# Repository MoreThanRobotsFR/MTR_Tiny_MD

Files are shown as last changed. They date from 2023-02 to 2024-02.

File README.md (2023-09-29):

# MTR_Tiny_MD
<p align="center">

 IMAGE ALT TEXT (https://www.youtube.com/watch?v=xt2y6jAOXSE "DRV8316 + RP2040 | SimpleFOC | MTR Tiny Motor Driver")

</p>

# Changelog

This changelog provides a summary of the updates and changes made to the Motor Driver - MTR Tiny Motor Driver.

## Revision History:

- Rev: 1.0.3 Date: 20/03/2023
    - Update: Stepper motor controller board
    - Update: Brushless motor controller board

- Rev: 1.1.0 Date: 10/05/2023
    - Update: Overview Board w/ BLDC + Support

- Rev: 1.2.0 Date: 14/09/2023
    - Update: Power Delivery controller
    - Update: Correct SPI wrong connection
    - Update: Update net design (power net)
    - Update: Rx & Tx pinout can be used for CAN

- Rev: 1.2.2 Date: 20/09/2023
    - Update: Add low pass filter for Reset button

# Overview

<p align="center">
    <a>
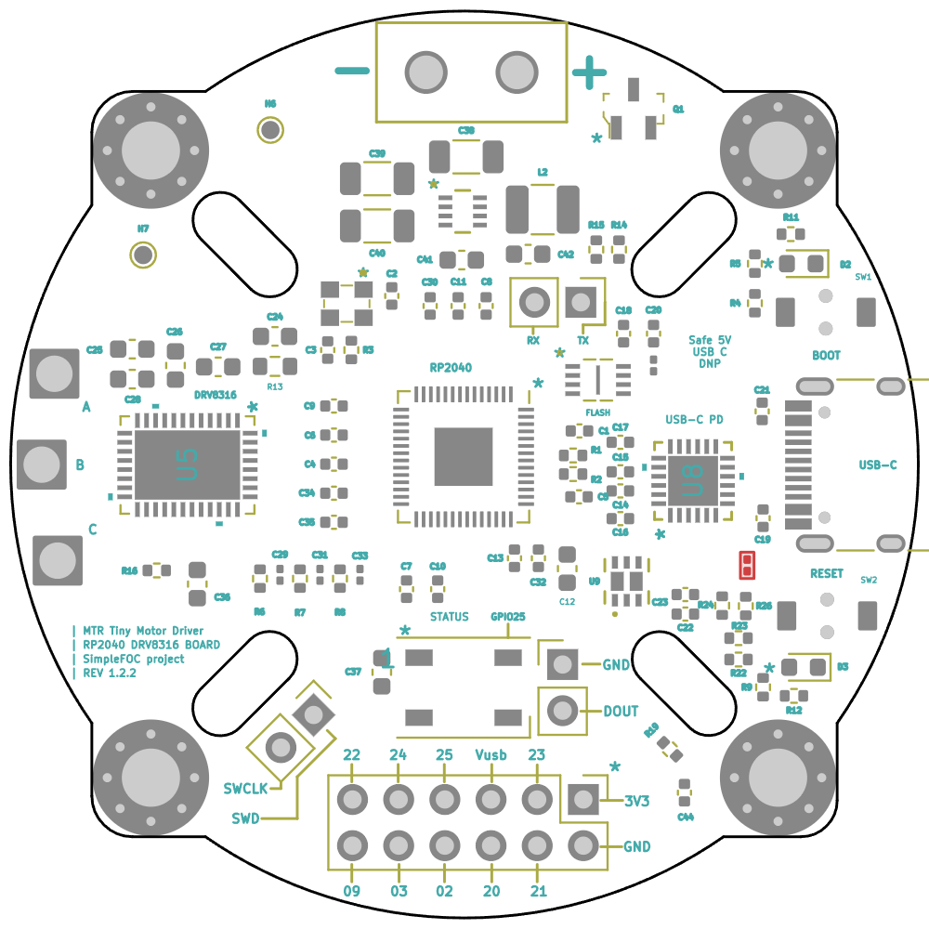
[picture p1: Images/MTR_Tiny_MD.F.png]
        
    </a>
    <br>
    <em>Front</em>
</p>

<p align="center">
    <a>
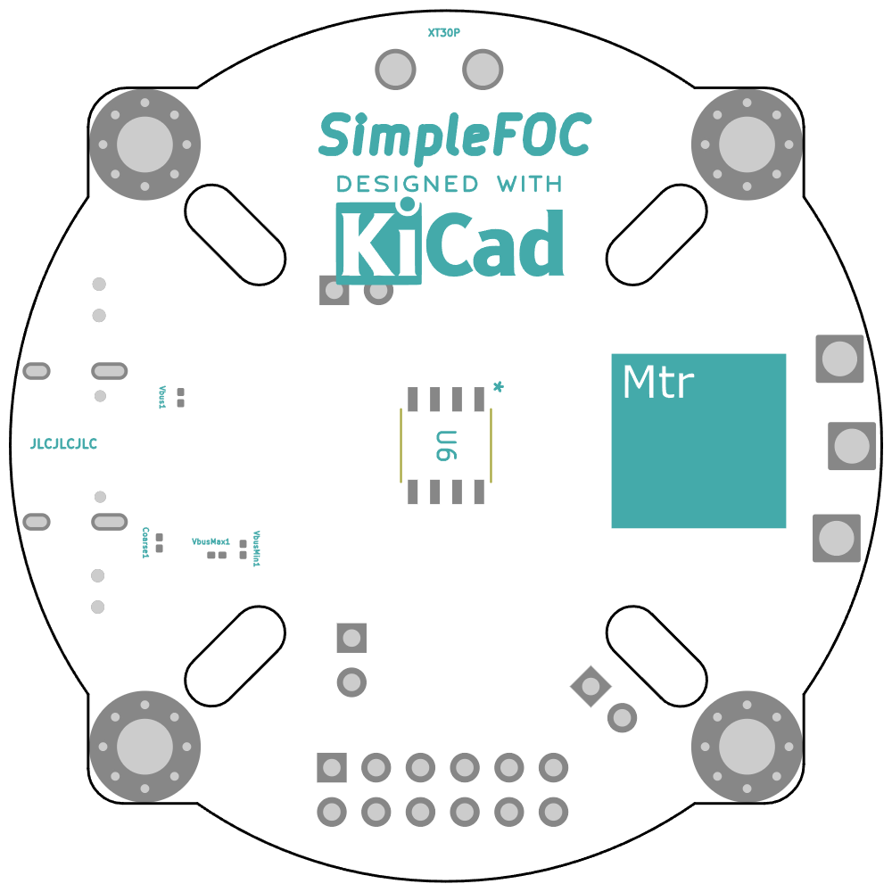
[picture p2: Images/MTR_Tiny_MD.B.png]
        
    </a>
    <br>
    <em>Back</em>
</p>

**Note:** 
- Please refer to the [schematic](Docs/MTR_Tiny_MD.pdf) for detailed information about the MTR Tiny Motor Driver.
- Please refer to the [presentation](Docs/MTR_MD.pdf) for detailed information about the MTR Tiny Motor Driver.
- Please refer to the [bill of materials](Hardware/MTR_Tiny_MD/bom/bom.html) for detailed information about the MTR Tiny Motor Driver.

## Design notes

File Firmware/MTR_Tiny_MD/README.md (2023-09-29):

# Code in Progress

This repository contains an Arduino code that is still in progress. The code is designed to control a BLDC (Brushless DC) motor using the SimpleFOC library and a DRV8316 driver. It also utilizes a magnetic sensor for position sensing and an Adafruit NeoPixel for visual feedback.

## Requirements
To run this code, you need the following components:
- Raspberry Pi RP2040 board (or any other Arduino board supported by the SimpleFOC library)
- DRV8316 driver board
- Magnetic sensor (AS5600 I2C)
- Adafruit NeoPixel strip

## Installation
1. Download and install PlatformIO IDE from the [official website](https://platformio.org/install).
2. Open PlatformIO IDE and create a new project.
3. Copy the code from this repository and replace the existing `main.cpp` file in your project with it.
4. Connect your Arduino board to your computer using a USB cable.
5. Open the `platformio.ini` file in your project and select the appropriate board and port under the `[env:your_board_name]` section.
6. Save the `platformio.ini` file.
7. Build and upload the code to your Arduino board using the PlatformIO IDE.

## Usage
1. Connect the DRV8316 driver board and the magnetic sensor to the appropriate pins on your Arduino board. Refer to the comments in the code for the pin assignments.
2. Connect the motor to the DRV8316 driver board.
3. Connect the Adafruit NeoPixel strip to the appropriate pin on your Arduino board. Refer to the comments in the code for the pin assignment.
4. Open the serial monitor in the PlatformIO IDE or use an external serial communication tool, such as Arduino Serial Monitor or PuTTY.
5. Set the baud rate to 115200.
6. Once the code is uploaded and running on your Arduino board, you can use the serial terminal to set the target velocity of the motor. Type "T" followed by the desired velocity and press enter.

## Current Status and Future Development
The code is currently a work in progress and may have bugs or incomplete functionality. The main functionality of controlling the BLDC motor using the SimpleFOC library and the DRV8316 driver is implemented. The code also includes features for monitoring motor variables and displaying the status of the DRV8316 driver using the serial monitor.

Future development plans for this code may include:
- Adding additional functionality, such as position control or torque control.
- Optimizing the code for better performance or efficiency.
- ...and more!

## Note
Please note that this code is still in progress and may not be fully functional or optimized. Use it at your own risk and make sure to test it in a controlled environment before using it in any critical or potentially dangerous applications. Contributions and feedback are welcome to help improve the code.

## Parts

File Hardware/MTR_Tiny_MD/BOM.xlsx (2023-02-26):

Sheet: BOM
Item | Qty | Reference(s) | Value | LibPart | Footprint | Datasheet
34 | 1 | Q1 | AO3401A | dk_Transistors-FETs-MOSFETs-Single:AO3401A | digikey-footprints:SOT-23-3 | http://aosmd.com/res/data_sheets/AO3401A.pdf
45 | 1 | U2 | W25Q16JVUXIQ | W25Q16JVUXIQ:W25Q16JVUXIQ | Personal:W25Q16JVUXIQ | https://www.mouser.fr/datasheet/2/949/w25q16jv_spi_revg_03222018_plus-1489727.pdf
47 | 1 | U4 | TPS71933-33DRVR | 2023-01-28_15-38-30:TPS71933-33DRVR | Personal:TPS71933-33DRVR
49 | 1 | U6 | AS5600L-ASOM | AS5600L-ASOM:AS5600L-ASOM | Personal:AS5600L-ASOM | https://www.mouser.fr/datasheet/2/588/AS5600L_DS000545_3_00-1893218.pdf
50 | 1 | Y1 | 8Z-12.000MAAJ-T | SamacSys_Parts:8Z-12.000MAAJ-T | SamacSys_Parts:8Z12000MAAJT | http://www.txccrystal.com/images/pdf/8z.pdf
1 | 10 | C1, C4, C6, C7, C8, C9, C10, C11, C13, C20 | 100n | Device:C_Small | Capacitor_SMD:C_0402_1005Metric | ~
2 | 2 | C2, C3 | 18p | Device:C_Small | Capacitor_SMD:C_0402_1005Metric | ~
3 | 1 | C5 | 1u | Device:C_Small | Capacitor_SMD:C_0402_1005Metric | ~
4 | 1 | C12 | 1u | Device:C_Small | Capacitor_SMD:C_0603_1608Metric | ~
5 | 1 | C14 | 2.2uF 50v | Device:C | Capacitor_SMD:C_0805_2012Metric | ~
6 | 2 | C15, C19 | 100nF 50v | Device:C | Capacitor_SMD:C_0603_1608Metric | ~
7 | 1 | C16 | 1uF 16v | Device:C | Capacitor_SMD:C_0603_1608Metric | ~
8 | 2 | C17, C22 | 10uF | Device:C | Capacitor_SMD:C_0603_1608Metric | ~
9 | 1 | C18 | 2u2 | Device:C_Small | Capacitor_SMD:C_0402_1005Metric | ~
10 | 2 | C21, C23 | 22uF 10v | Device:C | Capacitor_SMD:C_0603_1608Metric | ~
11 | 1 | C24 | 22uF | Device:C_Small | Capacitor_SMD:C_0603_1608Metric | ~
12 | 3 | C25, C28, C37 | 100nF | Device:C_Small | Capacitor_SMD:C_0603_1608Metric | ~
13 | 1 | C26 | 1uF | Device:C_Small | Capacitor_SMD:C_0603_1608Metric | ~
14 | 1 | C27 | 47nF | Device:C_Small | Capacitor_SMD:C_0603_1608Metric | ~
15 | 3 | C29, C31, C33 | 30pF | Device:C_Small | Capacitor_SMD:C_0201_0603Metric | ~
16 | 3 | C30, C34, C35 | 100nF | Device:C_Small | Capacitor_SMD:C_0402_1005Metric | ~
17 | 1 | C32 | 10uF | Device:C_Small | Capacitor_SMD:C_0402_1005Metric | ~
18 | 1 | C36 | 1.3uF | Device:C_Small | Capacitor_SMD:C_0603_1608Metric | ~
19 | 1 | D1 | WS2812B | LED:WS2812B | LED_SMD:LED_WS2812B_PLCC4_5.0x5.0mm_P3.2mm | https://cdn-shop.adafruit.com/datasheets/WS2812B.pdf
20 | 1 | D2 | Buck ON | Device:LED_Small | LED_SMD:LED_0603_1608Metric | ~
21 | 1 | D3 | USB ON | Device:LED_Small | LED_SMD:LED_0603_1608Metric | ~
22 | 4 | H1, H3, H8, H9 | MountingHole_Pad | Mechanical:MountingHole_Pad | MountingHole:MountingHole_3.2mm_M3_Pad_Via | ~
23 | 1 | H6 | Test_point_buck | Mechanical:MountingHole_Pad | TestPoint:TestPoint_Pad_1.5x1.5mm | ~
24 | 1 | H7 | Test_point_DRV_buck | Mechanical:MountingHole_Pad | TestPoint:TestPoint_Pad_1.5x1.5mm | ~
25 | 1 | H10 | OUTA | Mechanical:MountingHole_Pad | Personal:Motor_Wire_Solder_Pad | ~
26 | 1 | H11 | OUTB | Mechanical:MountingHole_Pad | Personal:Motor_Wire_Solder_Pad | ~
27 | 1 | H12 | OUTC | Mechanical:MountingHole_Pad | Personal:Motor_Wire_Solder_Pad | ~
28 | 1 | J1 | USB_C_Receptacle_USB2.0 | Connector:USB_C_Receptacle_USB2.0 | Connector_USB:USB_C_Receptacle_HRO_TYPE-C-31-M-12 | https://www.usb.org/sites/default/files/documents/usb_type-c.zip
29 | 1 | J2 | 68021-412HLF | dk_Rectangular-Connectors-Headers-Male-Pins:68021-412HLF | PinHeader:PinHeader_2x06_P2.54mm_Vertical | https://cdn.amphenol-icc.com/media/wysiwyg/files/drawing/68020.pdf
30 | 2 | J3, J5 | LED OUT | dk_Rectangular-Connectors-Headers-Male-Pins:22-23-2021 | PinHeader:PinHeader_1x02_P2.54mm_Vertical | https://media.digikey.com/pdf/Data%20Sheets/Molex%20PDFs/A-6373-N_Series_Dwg_2010-12-03.pdf
31 | 1 | J4 | UART | dk_Rectangular-Connectors-Headers-Male-Pins:22-23-2021 | PinHeader:PinHeader_1x02_P2.54mm_Vertical | https://media.digikey.com/pdf/Data%20Sheets/Molex%20PDFs/A-6373-N_Series_Dwg_2010-12-03.pdf
32 | 1 | J6 | XT30PB | DriverParts:XT30PB | Personal:XT30PB | https://www.tme.eu/Document/4acc913878197f8c2e30d4b8cdc47230/XT30UPB%20SPEC.pdf
33 | 1 | L1 | 15uH | pspice:INDUCTOR | Inductor_SMD:L_1210_3225Metric | ~
35 | 2 | R1, R2 | 27R | Device:R_Small | Resistor_SMD:R_0402_1005Metric | ~
36 | 7 | R3, R4, R5, R6, R7, R8, R9 | 1k | Device:R_Small | Resistor_SMD:R_0402_1005Metric | ~
37 | 1 | R11 | 470R | Device:R_Small | Resistor_SMD:R_0402_1005Metric | ~
38 | 1 | R12 | 820R | Device:R_Small | Resistor_SMD:R_0402_1005Metric | ~
39 | 1 | R13 | 22R | Device:R_Small | Resistor_SMD:R_0603_1608Metric | ~
40 | 2 | R14, R15 | 4.7k | Device:R_Small | Resistor_SMD:R_0402_1005Metric | ~
41 | 1 | R16 | 100R | Device:R_Small | Resistor_SMD:R_0402_1005Metric | ~
42 | 1 | SW1 | Boot | Switch:SW_Push | Personal:TVBM17 | ~
43 | 1 | SW2 | Reset | Switch:SW_Push | Personal:TVBM17 | ~
44 | 1 | U1 | RP2040 | MCU_RaspberryPi:RP2040 | Package_DFN_QFN:QFN-56-1EP_7x7mm_P0.4mm_EP3.2x3.2mm | https://datasheets.raspberrypi.com/rp2040/rp2040-datasheet.pdf
46 | 1 | U3 | LMR36506 | DriverParts:LMR36506 | Personal:LMR36506 | https://www.ti.com/lit/ds/symlink/lmr36506.pdf
48 | 1 | U5 | DRV8316RQRGFRQ1 | DVR8316R:DRV8316RQRGFRQ1 | Personal:DRV8316RQRGFRQ1 | https://www.ti.com/lit/ds/symlink/drv8316-q1.pdf?ts=1674332352245

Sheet: MTR_Tiny_MD (2)
Column1 | Column2 | Column3 | Column4 | Column5 | Column6 | Column7 | Column8 | Column9 | Column10 | Column11 | Column12 | Column13 | Column14 | Column15 | Column16 | Column17 | Column18 | Column19 | Column20 | Column21 | Column22 | Column23 | Column24
Source: | C:\Users\cicil\Desktop\MTR_Tiny_MD\MTR_Tiny_MD.kicad_sch
Date: | 04/02/2023 23:51:39
Tool: | Eeschema (6.0.9)
Generator: | C:\Program Files\KiCad\6.0\bin\scripting\plugins/bom_csv_grouped_by_value.py
Component Count: | 81
Individual Components:
Item | Qty | Reference(s) | Value | LibPart | Footprint | Datasheet | Arrow Part Number | Arrow Price/Stock | Category | DK_Datasheet_Link | DK_Detail_Page | Description | Digi-Key_PN | Family | Height | LCSC | MPN | Manufacturer | Manufacturer_Name | Manufacturer_Part_Number | Mouser Part Number | Mouser Price/Stock | Status
 |  | C1 | 100n | Device:C_Small | Capacitor_SMD:C_0402_1005Metric | ~
 |  | C2 | 18p | Device:C_Small | Capacitor_SMD:C_0402_1005Metric | ~
 |  | C3 | 18p | Device:C_Small | Capacitor_SMD:C_0402_1005Metric | ~
 |  | C4 | 100n | Device:C_Small | Capacitor_SMD:C_0402_1005Metric | ~
 |  | C5 | 1u | Device:C_Small | Capacitor_SMD:C_0402_1005Metric | ~
 |  | C6 | 100n | Device:C_Small | Capacitor_SMD:C_0402_1005Metric | ~
 |  | C7 | 100n | Device:C_Small | Capacitor_SMD:C_0402_1005Metric | ~
 |  | C8 | 100n | Device:C_Small | Capacitor_SMD:C_0402_1005Metric | ~
 |  | C9 | 100n | Device:C_Small | Capacitor_SMD:C_0402_1005Metric | ~
 |  | C10 | 100n | Device:C_Small | Capacitor_SMD:C_0402_1005Metric | ~
 |  | C11 | 100n | Device:C_Small | Capacitor_SMD:C_0402_1005Metric | ~
 |  | C12 | 1u | Device:C_Small | Capacitor_SMD:C_0603_1608Metric | ~
 |  | C13 | 100n | Device:C_Small | Capacitor_SMD:C_0402_1005Metric | ~
 |  | C14 | 2.2uF 50v | Device:C | Capacitor_SMD:C_0805_2012Metric | ~
 |  | C15 | 100nF 50v | Device:C | Capacitor_SMD:C_0603_1608Metric | ~
 |  | C16 | 1uF 16v | Device:C | Capacitor_SMD:C_0603_1608Metric | ~
 |  | C17 | 10uF | Device:C | Capacitor_SMD:C_0603_1608Metric | ~
 |  | C18 | 2u2 | Device:C_Small | Capacitor_SMD:C_0402_1005Metric | ~
 |  | C19 | 100nF 50v | Device:C | Capacitor_SMD:C_0603_1608Metric | ~
 |  | C20 | 100n | Device:C_Small | Capacitor_SMD:C_0402_1005Metric | ~
 |  | C21 | 22uF 10v | Device:C | Capacitor_SMD:C_0603_1608Metric | ~
 |  | C22 | 10uF | Device:C | Capacitor_SMD:C_0603_1608Metric | ~
 |  | C23 | 22uF 10v | Device:C | Capacitor_SMD:C_0603_1608Metric | ~
 |  | C24 | 22uF | Device:C_Small | Capacitor_SMD:C_0603_1608Metric | ~
 |  | C25 | 100nF | Device:C_Small | Capacitor_SMD:C_0603_1608Metric | ~
 |  | C26 | 1uF | Device:C_Small | Capacitor_SMD:C_0603_1608Metric | ~
 |  | C27 | 47nF | Device:C_Small | Capacitor_SMD:C_0603_1608Metric | ~
 |  | C28 | 100nF | Device:C_Small | Capacitor_SMD:C_0603_1608Metric | ~
 |  | C29 | 30pF | Device:C_Small | Capacitor_SMD:C_0201_0603Metric | ~
 |  | C30 | 100nF | Device:C_Small | Capacitor_SMD:C_0402_1005Metric | ~
 |  | C31 | 30pF | Device:C_Small | Capacitor_SMD:C_0201_0603Metric | ~
 |  | C32 | 10uF | Device:C_Small | Capacitor_SMD:C_0402_1005Metric | ~
 |  | C33 | 30pF | Device:C_Small | Capacitor_SMD:C_0201_0603Metric | ~
 |  | C34 | 100nF | Device:C_Small | Capacitor_SMD:C_0402_1005Metric | ~
 |  | C35 | 100nF | Device:C_Small | Capacitor_SMD:C_0402_1005Metric | ~
 |  | C36 | 1.3uF | Device:C_Small | Capacitor_SMD:C_0603_1608Metric | ~
 |  | C37 | 100nF | Device:C_Small | Capacitor_SMD:C_0603_1608Metric | ~
 |  | D1 | WS2812B | LED:WS2812B | LED_SMD:LED_WS2812B_PLCC4_5.0x5.0mm_P3.2mm | https://cdn-shop.adafruit.com/datasheets/WS2812B.pdf
 |  | D2 | Buck ON | Device:LED_Small | LED_SMD:LED_0603_1608Metric | ~
 |  | D3 | USB ON | Device:LED_Small | LED_SMD:LED_0603_1608Metric | ~
 |  | H1 | MountingHole_Pad | Mechanical:MountingHole_Pad | MountingHole:MountingHole_3.2mm_M3_Pad_Via | ~
 |  | H3 | MountingHole_Pad | Mechanical:MountingHole_Pad | MountingHole:MountingHole_3.2mm_M3_Pad_Via | ~
 |  | H6 | Test_point_buck | Mechanical:MountingHole_Pad | TestPoint:TestPoint_Pad_1.5x1.5mm | ~
 |  | H7 | Test_point_DRV_buck | Mechanical:MountingHole_Pad | TestPoint:TestPoint_Pad_1.5x1.5mm | ~
 |  | H8 | MountingHole_Pad | Mechanical:MountingHole_Pad | MountingHole:MountingHole_3.2mm_M3_Pad_Via | ~
 |  | H9 | MountingHole_Pad | Mechanical:MountingHole_Pad | MountingHole:MountingHole_3.2mm_M3_Pad_Via | ~
 |  | H10 | OUTA | Mechanical:MountingHole_Pad | Personal:Motor_Wire_Solder_Pad | ~
 |  | H11 | OUTB | Mechanical:MountingHole_Pad | Personal:Motor_Wire_Solder_Pad | ~
 |  | H12 | OUTC | Mechanical:MountingHole_Pad | Personal:Motor_Wire_Solder_Pad | ~
 |  | J1 | USB_C_Receptacle_USB2.0 | Connector:USB_C_Receptacle_USB2.0 | Connector_USB:USB_C_Receptacle_HRO_TYPE-C-31-M-12 | https://www.usb.org/sites/default/files/documents/usb_type-c.zip
 |  | J2 | 68021-412HLF | dk_Rectangular-Connectors-Headers-Male-Pins:68021-412HLF | PinHeader:PinHeader_2x06_P2.54mm_Vertical | https://cdn.amphenol-icc.com/media/wysiwyg/files/drawing/68020.pdf |  |  | Connectors, Interconnects | https://cdn.amphenol-icc.com/media/wysiwyg/files/drawing/68020.pdf | /product-detail/en/amphenol-icc-fci/68021-412HLF/609-3355-ND/1878558 | CONN HEADER R/A 12POS 2.54MM | 609-3355-ND | Rectangular Connectors - Headers, Male Pins |  |  | 68021-412HLF | Amphenol ICC (FCI) |  |  |  |  | Active
 |  | J3 | LED OUT | dk_Rectangular-Connectors-Headers-Male-Pins:22-23-2021 | PinHeader:PinHeader_1x02_P2.54mm_Vertical | https://media.digikey.com/pdf/Data%20Sheets/Molex%20PDFs/A-6373-N_Series_Dwg_2010-12-03.pdf |  |  | Connectors, Interconnects | https://media.digikey.com/pdf/Data%20Sheets/Molex%20PDFs/A-6373-N_Series_Dwg_2010-12-03.pdf | /product-detail/en/molex/22-23-2021/WM4200-ND/26667 | CONN HEADER VERT 2POS 2.54MM | WM4200-ND | Rectangular Connectors - Headers, Male Pins |  |  | 22-23-2021 | Molex |  |  |  |  | Active
 |  | J4 | UART | dk_Rectangular-Connectors-Headers-Male-Pins:22-23-2021 | PinHeader:PinHeader_1x02_P2.54mm_Vertical | https://media.digikey.com/pdf/Data%20Sheets/Molex%20PDFs/A-6373-N_Series_Dwg_2010-12-03.pdf |  |  | Connectors, Interconnects | https://media.digikey.com/pdf/Data%20Sheets/Molex%20PDFs/A-6373-N_Series_Dwg_2010-12-03.pdf | /product-detail/en/molex/22-23-2021/WM4200-ND/26667 | CONN HEADER VERT 2POS 2.54MM | WM4200-ND | Rectangular Connectors - Headers, Male Pins |  |  | 22-23-2021 | Molex |  |  |  |  | Active
 |  | J5 | LED OUT | dk_Rectangular-Connectors-Headers-Male-Pins:22-23-2021 | PinHeader:PinHeader_1x02_P2.54mm_Vertical | https://media.digikey.com/pdf/Data%20Sheets/Molex%20PDFs/A-6373-N_Series_Dwg_2010-12-03.pdf |  |  | Connectors, Interconnects | https://media.digikey.com/pdf/Data%20Sheets/Molex%20PDFs/A-6373-N_Series_Dwg_2010-12-03.pdf | /product-detail/en/molex/22-23-2021/WM4200-ND/26667 | CONN HEADER VERT 2POS 2.54MM | WM4200-ND | Rectangular Connectors - Headers, Male Pins |  |  | 22-23-2021 | Molex |  |  |  |  | Active
 |  | J6 | XT30PB | DriverParts:XT30PB | Personal:XT30PB | https://www.tme.eu/Document/4acc913878197f8c2e30d4b8cdc47230/XT30UPB%20SPEC.pdf |  |  |  |  |  | Mini XT30 Connector |  |  | 10.7 |  |  |  | Amass | XT30PB
 |  | L1 | 15uH | pspice:INDUCTOR | Inductor_SMD:L_1210_3225Metric | ~ |  |  |  |  |  |  |  |  |  | C83083 | NLCV32T-470K-PF | TDK
 |  | Q1 | AO3401A | dk_Transistors-FETs-MOSFETs-Single:AO3401A | digikey-footprints:SOT-23-3 | http://aosmd.com/res/data_sheets/AO3401A.pdf |  |  | Discrete Semiconductor Products | http://aosmd.com/res/data_sheets/AO3401A.pdf | /product-detail/en/alpha-omega-semiconductor-inc/AO3401A/785-1001-1-ND/1855943 | MOSFET P-CH 30V 4A SOT23 | 785-1001-1-ND | Transistors - FETs, MOSFETs - Single |  |  | AO3401A | Alpha & Omega Semiconductor Inc. |  |  |  |  | Active
 |  | R1 | 27R | Device:R_Small | Resistor_SMD:R_0402_1005Metric | ~
 |  | R2 | 27R | Device:R_Small | Resistor_SMD:R_0402_1005Metric | ~
 |  | R3 | 1k | Device:R_Small | Resistor_SMD:R_0402_1005Metric | ~
 |  | R4 | 1k | Device:R_Small | Resistor_SMD:R_0402_1005Metric | ~
 |  | R5 | 1k | Device:R_Small | Resistor_SMD:R_0402_1005Metric | ~
 |  | R6 | 1k | Device:R_Small | Resistor_SMD:R_0402_1005Metric | ~
 |  | R7 | 1k | Device:R_Small | Resistor_SMD:R_0402_1005Metric | ~
 |  | R8 | 1k | Device:R_Small | Resistor_SMD:R_0402_1005Metric | ~
 |  | R9 | 1k | Device:R_Small | Resistor_SMD:R_0402_1005Metric | ~
 |  | R11 | 470R | Device:R_Small | Resistor_SMD:R_0402_1005Metric | ~
 |  | R12 | 820R | Device:R_Small | Resistor_SMD:R_0402_1005Metric | ~
 |  | R13 | 22R | Device:R_Small | Resistor_SMD:R_0603_1608Metric | ~
 |  | R14 | 4.7k | Device:R_Small | Resistor_SMD:R_0402_1005Metric | ~
 |  | R15 | 4.7k | Device:R_Small | Resistor_SMD:R_0402_1005Metric | ~
 |  | R16 | 100R | Device:R_Small | Resistor_SMD:R_0402_1005Metric | ~
 |  | SW1 | Boot | Switch:SW_Push | Personal:TVBM17 | ~
 |  | SW2 | Reset | Switch:SW_Push | Personal:TVBM17 | ~
 |  | U1 | RP2040 | MCU_RaspberryPi:RP2040 | Package_DFN_QFN:QFN-56-1EP_7x7mm_P0.4mm_EP3.2x3.2mm | https://datasheets.raspberrypi.com/rp2040/rp2040-datasheet.pdf
 |  | U2 | W25Q16JVUXIQ | W25Q16JVUXIQ:W25Q16JVUXIQ | Personal:W25Q16JVUXIQ | https://www.mouser.fr/datasheet/2/949/w25q16jv_spi_revg_03222018_plus-1489727.pdf
 |  | U3 | LMR36506 | DriverParts:LMR36506 | Personal:LMR36506 | https://www.ti.com/lit/ds/symlink/lmr36506.pdf
 |  | U4 | TPS71933-33DRVR | 2023-01-28_15-38-30:TPS71933-33DRVR | Personal:TPS71933-33DRVR
 |  | U5 | DRV8316RQRGFRQ1 | DVR8316R:DRV8316RQRGFRQ1 | Personal:DRV8316RQRGFRQ1 | https://www.ti.com/lit/ds/symlink/drv8316-q1.pdf?ts=1674332352245
 |  | U6 | AS5600L-ASOM | AS5600L-ASOM:AS5600L-ASOM | Personal:AS5600L-ASOM | https://www.mouser.fr/datasheet/2/588/AS5600L_DS000545_3_00-1893218.pdf
 |  | Y1 | 8Z-12.000MAAJ-T | SamacSys_Parts:8Z-12.000MAAJ-T | SamacSys_Parts:8Z12000MAAJT | http://www.txccrystal.com/images/pdf/8z.pdf | 8Z-12.000MAAJ-T | https://www.arrow.com/en/products/8z-12.000maaj-t/txc-corporation?region=nac |  |  |  | TXC - 8Z-12.000MAAJ-T - CRYSTAL, 12MHZ, 18PF, 2.5 X 2MM |  |  | 0.55 |  |  |  | TXC CORPORATION | 8Z-12.000MAAJ-T | 717-8Z-12.000MAAJ-T | https://www.mouser.co.uk/ProductDetail/TXC-Corporation/8Z-12.000MAAJ-T?qs=AbXXCOATRpjXyht3Ejd1DQ%3D%3D
Collated Components:
Item | Qty | Reference(s) | Value | LibPart | Footprint | Datasheet | Arrow Part Number | Arrow Price/Stock | Category | DK_Datasheet_Link | DK_Detail_Page | Description | Digi-Key_PN | Family | Height | LCSC | MPN | Manufacturer | Manufacturer_Name | Manufacturer_Part_Number | Mouser Part Number | Mouser Price/Stock | Status
1 | 10 | C1, C4, C6, C7, C8, C9, C10, C11, C13, C20 | 100n | Device:C_Small | Capacitor_SMD:C_0402_1005Metric | ~
2 | 2 | C2, C3 | 18p | Device:C_Small | Capacitor_SMD:C_0402_1005Metric | ~
3 | 1 | C5 | 1u | Device:C_Small | Capacitor_SMD:C_0402_1005Metric | ~
4 | 1 | C12 | 1u | Device:C_Small | Capacitor_SMD:C_0603_1608Metric | ~
5 | 1 | C14 | 2.2uF 50v | Device:C | Capacitor_SMD:C_0805_2012Metric | ~
6 | 2 | C15, C19 | 100nF 50v | Device:C | Capacitor_SMD:C_0603_1608Metric | ~
7 | 1 | C16 | 1uF 16v | Device:C | Capacitor_SMD:C_0603_1608Metric | ~
8 | 2 | C17, C22 | 10uF | Device:C | Capacitor_SMD:C_0603_1608Metric | ~
9 | 1 | C18 | 2u2 | Device:C_Small | Capacitor_SMD:C_0402_1005Metric | ~
10 | 2 | C21, C23 | 22uF 10v | Device:C | Capacitor_SMD:C_0603_1608Metric | ~
11 | 1 | C24 | 22uF | Device:C_Small | Capacitor_SMD:C_0603_1608Metric | ~
12 | 3 | C25, C28, C37 | 100nF | Device:C_Small | Capacitor_SMD:C_0603_1608Metric | ~
13 | 1 | C26 | 1uF | Device:C_Small | Capacitor_SMD:C_0603_1608Metric | ~
14 | 1 | C27 | 47nF | Device:C_Small | Capacitor_SMD:C_0603_1608Metric | ~
15 | 3 | C29, C31, C33 | 30pF | Device:C_Small | Capacitor_SMD:C_0201_0603Metric | ~
16 | 3 | C30, C34, C35 | 100nF | Device:C_Small | Capacitor_SMD:C_0402_1005Metric | ~
17 | 1 | C32 | 10uF | Device:C_Small | Capacitor_SMD:C_0402_1005Metric | ~
18 | 1 | C36 | 1.3uF | Device:C_Small | Capacitor_SMD:C_0603_1608Metric | ~
19 | 1 | D1 | WS2812B | LED:WS2812B | LED_SMD:LED_WS2812B_PLCC4_5.0x5.0mm_P3.2mm | https://cdn-shop.adafruit.com/datasheets/WS2812B.pdf
20 | 1 | D2 | Buck ON | Device:LED_Small | LED_SMD:LED_0603_1608Metric | ~
21 | 1 | D3 | USB ON | Device:LED_Small | LED_SMD:LED_0603_1608Metric | ~
22 | 4 | H1, H3, H8, H9 | MountingHole_Pad | Mechanical:MountingHole_Pad | MountingHole:MountingHole_3.2mm_M3_Pad_Via | ~
23 | 1 | H6 | Test_point_buck | Mechanical:MountingHole_Pad | TestPoint:TestPoint_Pad_1.5x1.5mm | ~
24 | 1 | H7 | Test_point_DRV_buck | Mechanical:MountingHole_Pad | TestPoint:TestPoint_Pad_1.5x1.5mm | ~
25 | 1 | H10 | OUTA | Mechanical:MountingHole_Pad | Personal:Motor_Wire_Solder_Pad | ~
26 | 1 | H11 | OUTB | Mechanical:MountingHole_Pad | Personal:Motor_Wire_Solder_Pad | ~
27 | 1 | H12 | OUTC | Mechanical:MountingHole_Pad | Personal:Motor_Wire_Solder_Pad | ~
28 | 1 | J1 | USB_C_Receptacle_USB2.0 | Connector:USB_C_Receptacle_USB2.0 | Connector_USB:USB_C_Receptacle_HRO_TYPE-C-31-M-12 | https://www.usb.org/sites/default/files/documents/usb_type-c.zip
29 | 1 | J2 | 68021-412HLF | dk_Rectangular-Connectors-Headers-Male-Pins:68021-412HLF | PinHeader:PinHeader_2x06_P2.54mm_Vertical | https://cdn.amphenol-icc.com/media/wysiwyg/files/drawing/68020.pdf |  |  | Connectors, Interconnects | https://cdn.amphenol-icc.com/media/wysiwyg/files/drawing/68020.pdf | /product-detail/en/amphenol-icc-fci/68021-412HLF/609-3355-ND/1878558 | CONN HEADER R/A 12POS 2.54MM | 609-3355-ND | Rectangular Connectors - Headers, Male Pins |  |  | 68021-412HLF | Amphenol ICC (FCI) |  |  |  |  | Active
30 | 2 | J3, J5 | LED OUT | dk_Rectangular-Connectors-Headers-Male-Pins:22-23-2021 | PinHeader:PinHeader_1x02_P2.54mm_Vertical | https://media.digikey.com/pdf/Data%20Sheets/Molex%20PDFs/A-6373-N_Series_Dwg_2010-12-03.pdf |  |  | Connectors, Interconnects | https://media.digikey.com/pdf/Data%20Sheets/Molex%20PDFs/A-6373-N_Series_Dwg_2010-12-03.pdf | /product-detail/en/molex/22-23-2021/WM4200-ND/26667 | CONN HEADER VERT 2POS 2.54MM | WM4200-ND | Rectangular Connectors - Headers, Male Pins |  |  | 22-23-2021 | Molex |  |  |  |  | Active
31 | 1 | J4 | UART | dk_Rectangular-Connectors-Headers-Male-Pins:22-23-2021 | PinHeader:PinHeader_1x02_P2.54mm_Vertical | https://media.digikey.com/pdf/Data%20Sheets/Molex%20PDFs/A-6373-N_Series_Dwg_2010-12-03.pdf |  |  | Connectors, Interconnects | https://media.digikey.com/pdf/Data%20Sheets/Molex%20PDFs/A-6373-N_Series_Dwg_2010-12-03.pdf | /product-detail/en/molex/22-23-2021/WM4200-ND/26667 | CONN HEADER VERT 2POS 2.54MM | WM4200-ND | Rectangular Connectors - Headers, Male Pins |  |  | 22-23-2021 | Molex |  |  |  |  | Active
32 | 1 | J6 | XT30PB | DriverParts:XT30PB | Personal:XT30PB | https://www.tme.eu/Document/4acc913878197f8c2e30d4b8cdc47230/XT30UPB%20SPEC.pdf |  |  |  |  |  | Mini XT30 Connector |  |  | 10.7 |  |  |  | Amass | XT30PB
33 | 1 | L1 | 15uH | pspice:INDUCTOR | Inductor_SMD:L_1210_3225Metric | ~ |  |  |  |  |  |  |  |  |  | C83083 | NLCV32T-470K-PF | TDK
34 | 1 | Q1 | AO3401A | dk_Transistors-FETs-MOSFETs-Single:AO3401A | digikey-footprints:SOT-23-3 | http://aosmd.com/res/data_sheets/AO3401A.pdf |  |  | Discrete Semiconductor Products | http://aosmd.com/res/data_sheets/AO3401A.pdf | /product-detail/en/alpha-omega-semiconductor-inc/AO3401A/785-1001-1-ND/1855943 | MOSFET P-CH 30V 4A SOT23 | 785-1001-1-ND | Transistors - FETs, MOSFETs - Single |  |  | AO3401A | Alpha & Omega Semiconductor Inc. |  |  |  |  | Active
35 | 2 | R1, R2 | 27R | Device:R_Small | Resistor_SMD:R_0402_1005Metric | ~
36 | 7 | R3, R4, R5, R6, R7, R8, R9 | 1k | Device:R_Small | Resistor_SMD:R_0402_1005Metric | ~
37 | 1 | R11 | 470R | Device:R_Small | Resistor_SMD:R_0402_1005Metric | ~
38 | 1 | R12 | 820R | Device:R_Small | Resistor_SMD:R_0402_1005Metric | ~
39 | 1 | R13 | 22R | Device:R_Small | Resistor_SMD:R_0603_1608Metric | ~
40 | 2 | R14, R15 | 4.7k | Device:R_Small | Resistor_SMD:R_0402_1005Metric | ~
41 | 1 | R16 | 100R | Device:R_Small | Resistor_SMD:R_0402_1005Metric | ~
42 | 1 | SW1 | Boot | Switch:SW_Push | Personal:TVBM17 | ~
43 | 1 | SW2 | Reset | Switch:SW_Push | Personal:TVBM17 | ~
44 | 1 | U1 | RP2040 | MCU_RaspberryPi:RP2040 | Package_DFN_QFN:QFN-56-1EP_7x7mm_P0.4mm_EP3.2x3.2mm | https://datasheets.raspberrypi.com/rp2040/rp2040-datasheet.pdf
45 | 1 | U2 | W25Q16JVUXIQ | W25Q16JVUXIQ:W25Q16JVUXIQ | Personal:W25Q16JVUXIQ | https://www.mouser.fr/datasheet/2/949/w25q16jv_spi_revg_03222018_plus-1489727.pdf
46 | 1 | U3 | LMR36506 | DriverParts:LMR36506 | Personal:LMR36506 | https://www.ti.com/lit/ds/symlink/lmr36506.pdf
47 | 1 | U4 | TPS71933-33DRVR | 2023-01-28_15-38-30:TPS71933-33DRVR | Personal:TPS71933-33DRVR
48 | 1 | U5 | DRV8316RQRGFRQ1 | DVR8316R:DRV8316RQRGFRQ1 | Personal:DRV8316RQRGFRQ1 | https://www.ti.com/lit/ds/symlink/drv8316-q1.pdf?ts=1674332352245
49 | 1 | U6 | AS5600L-ASOM | AS5600L-ASOM:AS5600L-ASOM | Personal:AS5600L-ASOM | https://www.mouser.fr/datasheet/2/588/AS5600L_DS000545_3_00-1893218.pdf
50 | 1 | Y1 | 8Z-12.000MAAJ-T | SamacSys_Parts:8Z-12.000MAAJ-T | SamacSys_Parts:8Z12000MAAJT | http://www.txccrystal.com/images/pdf/8z.pdf | 8Z-12.000MAAJ-T | https://www.arrow.com/en/products/8z-12.000maaj-t/txc-corporation?region=nac |  |  |  | TXC - 8Z-12.000MAAJ-T - CRYSTAL, 12MHZ, 18PF, 2.5 X 2MM |  |  | 0.55 |  |  |  | TXC CORPORATION | 8Z-12.000MAAJ-T | 717-8Z-12.000MAAJ-T | https://www.mouser.co.uk/ProductDetail/TXC-Corporation/8Z-12.000MAAJ-T?qs=AbXXCOATRpjXyht3Ejd1DQ%3D%3D

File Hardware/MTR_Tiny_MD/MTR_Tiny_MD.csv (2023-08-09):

Reference | Value | Footprint | Datasheet | Arrow Part Number | Arrow Price/Stock | Category | DK_Datasheet_Link | DK_Detail_Page | Description | Digi-Key_PN | Family | Height | MPN | Manufacturer | Manufacturer_Name | Manufacturer_Part_Number | Mouser Part Number | Mouser Price/Stock | Mouser Testing Part Number | Mouser Testing Price/Stock | Status | Qté
C1, C4, C6-C11, C13, C20 | 100n | Capacitor_SMD:C_0402_1005Metric | ~ |  |  |  |  |  |  |  |  |  |  |  |  |  |  |  |  |  |  | 10
C2, C3 | 18p | Capacitor_SMD:C_0402_1005Metric | ~ |  |  |  |  |  |  |  |  |  |  |  |  |  |  |  |  |  |  | 2
C5 | 1u | Capacitor_SMD:C_0402_1005Metric | ~ |  |  |  |  |  |  |  |  |  |  |  |  |  |  |  |  |  |  | 1
C12 | 1u | Capacitor_SMD:C_0603_1608Metric | ~ |  |  |  |  |  |  |  |  |  |  |  |  |  |  |  |  |  |  | 1
C17, C22 | 10uF | Capacitor_SMD:C_0603_1608Metric | ~ |  |  |  |  |  |  |  |  |  |  |  |  |  |  |  |  |  |  | 2
C18 | 2u2 | Capacitor_SMD:C_0402_1005Metric | ~ |  |  |  |  |  |  |  |  |  |  |  |  |  |  |  |  |  |  | 1
C24 | 22uF | Capacitor_SMD:C_0603_1608Metric | ~ |  |  |  |  |  |  |  |  |  |  |  |  |  |  |  |  |  |  | 1
C25, C28, C37 | 100nF | Capacitor_SMD:C_0603_1608Metric | ~ |  |  |  |  |  |  |  |  |  |  |  |  |  |  |  |  |  |  | 3
C26 | 1uF | Capacitor_SMD:C_0603_1608Metric | ~ |  |  |  |  |  |  |  |  |  |  |  |  |  |  |  |  |  |  | 1
C27 | 47nF | Capacitor_SMD:C_0603_1608Metric | ~ |  |  |  |  |  |  |  |  |  |  |  |  |  |  |  |  |  |  | 1
C29, C31, C33 | 30pF | Capacitor_SMD:C_0201_0603Metric | ~ |  |  |  |  |  |  |  |  |  |  |  |  |  |  |  |  |  |  | 3
C30, C34, C35 | 100nF | Capacitor_SMD:C_0402_1005Metric | ~ |  |  |  |  |  |  |  |  |  |  |  |  |  |  |  |  |  |  | 3
C32 | 10uF | Capacitor_SMD:C_0402_1005Metric | ~ |  |  |  |  |  |  |  |  |  |  |  |  |  |  |  |  |  |  | 1
C36 | 2u2F | Capacitor_SMD:C_0603_1608Metric | ~ |  |  |  |  |  |  |  |  |  |  |  |  |  |  |  |  |  |  | 1
C38, C39 | 1uF 50V | Capacitor_SMD:C_1206_3216Metric | ~ |  |  |  |  |  |  |  |  |  |  |  |  |  |  |  |  |  |  | 2
C40 | 10uF 10V | Capacitor_SMD:C_1206_3216Metric | ~ |  |  |  |  |  |  |  |  |  |  |  |  |  |  |  |  |  |  | 1
C41, C42 | 22uF 10v | Capacitor_SMD:C_0603_1608Metric | ~ |  |  |  |  |  |  |  |  |  |  |  |  |  |  |  |  |  |  | 2
D1 | WS2812B | LED_SMD:LED_WS2812B_PLCC4_5.0x5.0mm_P3.2mm | https://cdn-shop.adafruit.com/datasheets/WS2812B.pdf |  |  |  |  |  |  |  |  |  |  |  |  |  |  |  |  |  |  | 1
D2 | Buck ON | LED_SMD:LED_0603_1608Metric | ~ |  |  |  |  |  |  |  |  |  |  |  |  |  |  |  |  |  |  | 1
D3 | USB ON | LED_SMD:LED_0603_1608Metric | ~ |  |  |  |  |  |  |  |  |  |  |  |  |  |  |  |  |  |  | 1
F1 | 500mA | Fuse:Fuse_0603_1608Metric | ~ |  |  |  |  |  |  |  |  |  |  |  |  |  |  |  |  |  |  | 1
F2 | 250mA | Fuse:Fuse_0603_1608Metric | ~ |  |  |  |  |  |  |  |  |  |  |  |  |  |  |  |  |  |  | 1
H1, H3, H8, H9 | MountingHole_Pad | MountingHole:MountingHole_3.2mm_M3_Pad_Via | ~ |  |  |  |  |  |  |  |  |  |  |  |  |  |  |  |  |  |  | 4
H6 | Test_point_buck | TestPoint:TestPoint_Pad_1.5x1.5mm | ~ |  |  |  |  |  |  |  |  |  |  |  |  |  |  |  |  |  |  | 1
H7 | Test_point_DRV_buck | TestPoint:TestPoint_Pad_1.5x1.5mm | ~ |  |  |  |  |  |  |  |  |  |  |  |  |  |  |  |  |  |  | 1
H10 | OUTA | Personal:Motor_Wire_Solder_Pad | ~ |  |  |  |  |  |  |  |  |  |  |  |  |  |  |  |  |  |  | 1
H11 | OUTB | Personal:Motor_Wire_Solder_Pad | ~ |  |  |  |  |  |  |  |  |  |  |  |  |  |  |  |  |  |  | 1
H12 | OUTC | Personal:Motor_Wire_Solder_Pad | ~ |  |  |  |  |  |  |  |  |  |  |  |  |  |  |  |  |  |  | 1
J1 | USB_C_Receptacle_USB2.0 | Connector_USB:USB_C_Receptacle_HRO_TYPE-C-31-M-12 | https://www.usb.org/sites/default/files/documents/usb_type-c.zip |  |  |  |  |  |  |  |  |  |  |  |  |  |  |  |  |  |  | 1
J2 | 68021-412HLF | PinHeader:PinHeader_2x06_P2.54mm_Vertical | https://cdn.amphenol-icc.com/media/wysiwyg/files/drawing/68020.pdf |  |  | Connectors, Interconnects | https://cdn.amphenol-icc.com/media/wysiwyg/files/drawing/68020.pdf | /product-detail/en/amphenol-icc-fci/68021-412HLF/609-3355-ND/1878558 | CONN HEADER R/A 12POS 2.54MM | 609-3355-ND | Rectangular Connectors - Headers, Male Pins |  | 68021-412HLF | Amphenol ICC (FCI) |  |  |  |  |  |  | Active | 1
J3, J5 | LED OUT | PinHeader:PinHeader_1x02_P2.54mm_Vertical | https://media.digikey.com/pdf/Data%20Sheets/Molex%20PDFs/A-6373-N_Series_Dwg_2010-12-03.pdf |  |  | Connectors, Interconnects | https://media.digikey.com/pdf/Data%20Sheets/Molex%20PDFs/A-6373-N_Series_Dwg_2010-12-03.pdf | /product-detail/en/molex/22-23-2021/WM4200-ND/26667 | CONN HEADER VERT 2POS 2.54MM | WM4200-ND | Rectangular Connectors - Headers, Male Pins |  | 22-23-2021 | Molex |  |  |  |  |  |  | Active | 2
J4 | UART | PinHeader:PinHeader_1x02_P2.54mm_Vertical | https://media.digikey.com/pdf/Data%20Sheets/Molex%20PDFs/A-6373-N_Series_Dwg_2010-12-03.pdf |  |  | Connectors, Interconnects | https://media.digikey.com/pdf/Data%20Sheets/Molex%20PDFs/A-6373-N_Series_Dwg_2010-12-03.pdf | /product-detail/en/molex/22-23-2021/WM4200-ND/26667 | CONN HEADER VERT 2POS 2.54MM | WM4200-ND | Rectangular Connectors - Headers, Male Pins |  | 22-23-2021 | Molex |  |  |  |  |  |  | Active | 1
J6 | XT30PB | Personal:XT30PB | https://www.tme.eu/Document/4acc913878197f8c2e30d4b8cdc47230/XT30UPB%20SPEC.pdf |  |  |  |  |  | Mini XT30 Connector |  |  | 10.7 |  |  | Amass | XT30PB |  |  |  |  |  | 1
L2 | 33uH | Inductor_SMD:L_1210_3225Metric | ~ |  |  |  |  |  |  |  |  |  |  |  |  |  |  |  |  |  |  | 1
Q1 | AO3401A | digikey-footprints:SOT-23-3 | http://aosmd.com/res/data_sheets/AO3401A.pdf |  |  | Discrete Semiconductor Products | http://aosmd.com/res/data_sheets/AO3401A.pdf | /product-detail/en/alpha-omega-semiconductor-inc/AO3401A/785-1001-1-ND/1855943 | MOSFET P-CH 30V 4A SOT23 | 785-1001-1-ND | Transistors - FETs, MOSFETs - Single |  | AO3401A | Alpha & Omega Semiconductor Inc. |  |  |  |  |  |  | Active | 1
R1, R2 | 27R | Resistor_SMD:R_0402_1005Metric | ~ |  |  |  |  |  |  |  |  |  |  |  |  |  |  |  |  |  |  | 2
R3-R9 | 1k | Resistor_SMD:R_0402_1005Metric | ~ |  |  |  |  |  |  |  |  |  |  |  |  |  |  |  |  |  |  | 7
R11 | 470R | Resistor_SMD:R_0402_1005Metric | ~ |  |  |  |  |  |  |  |  |  |  |  |  |  |  |  |  |  |  | 1
R12 | 820R | Resistor_SMD:R_0402_1005Metric | ~ |  |  |  |  |  |  |  |  |  |  |  |  |  |  |  |  |  |  | 1
R13 | 22R | Resistor_SMD:R_0603_1608Metric | ~ |  |  |  |  |  |  |  |  |  |  |  |  |  |  |  |  |  |  | 1
R14, R15 | 4.7k | Resistor_SMD:R_0402_1005Metric | ~ |  |  |  |  |  |  |  |  |  |  |  |  |  |  |  |  |  |  | 2
R16 | 100R | Resistor_SMD:R_0402_1005Metric | ~ |  |  |  |  |  |  |  |  |  |  |  |  |  |  |  |  |  |  | 1
SW1 | Boot | Personal:TVBM17 | ~ |  |  |  |  |  |  |  |  |  |  |  |  |  |  |  |  |  |  | 1
SW2 | Reset | Personal:TVBM17 | ~ |  |  |  |  |  |  |  |  |  |  |  |  |  |  |  |  |  |  | 1
U1 | RP2040 | Package_DFN_QFN:QFN-56-1EP_7x7mm_P0.4mm_EP3.2x3.2mm | https://datasheets.raspberrypi.com/rp2040/rp2040-datasheet.pdf |  |  |  |  |  |  |  |  |  |  |  |  |  |  |  |  |  |  | 1
U2 | W25Q16JVUXIQ | Personal:W25Q16JVUXIQ | https://www.mouser.fr/datasheet/2/949/w25q16jv_spi_revg_03222018_plus-1489727.pdf |  |  |  |  |  |  |  |  |  |  |  |  |  |  |  |  |  |  | 1
U4 | TPS71933-33DRVR | Personal:TPS71933-33DRVR |  |  |  |  |  |  |  |  |  |  |  |  |  |  |  |  |  |  |  | 1
U5 | DRV8316RQRGFRQ1 | Personal:DRV8316RQRGFRQ1 | https://www.ti.com/lit/ds/symlink/drv8316-q1.pdf?ts=1674332352245 |  |  |  |  |  |  |  |  |  |  |  |  |  |  |  |  |  |  | 1
U6 | AS5600L-ASOM | Personal:AS5600L-ASOM | https://www.mouser.fr/datasheet/2/588/AS5600L_DS000545_3_00-1893218.pdf |  |  |  |  |  |  |  |  |  |  |  |  |  |  |  |  |  |  | 1
U7 | MAX15462AATA+T | footprints:21-0487_T822CN&plus_1_MXM | MAX15462AATA+T |  |  |  |  |  |  |  |  |  |  |  |  |  |  |  |  |  |  | 1
Y1 | 8Z-12.000MAAJ-T | SamacSys_Parts:8Z12000MAAJT | http://www.txccrystal.com/images/pdf/8z.pdf | 8Z-12.000MAAJ-T | https://www.arrow.com/en/products/8z-12.000maaj-t/txc-corporation?region=nac |  |  |  | TXC - 8Z-12.000MAAJ-T - CRYSTAL, 12MHZ, 18PF, 2.5 X 2MM |  |  | 0.55 |  |  | TXC CORPORATION | 8Z-12.000MAAJ-T | 717-8Z-12.000MAAJ-T | https://www.mouser.co.uk/ProductDetail/TXC-Corporation/8Z-12.000MAAJ-T?qs=AbXXCOATRpjXyht3Ejd1DQ%3D%3D |  |  |  | 1

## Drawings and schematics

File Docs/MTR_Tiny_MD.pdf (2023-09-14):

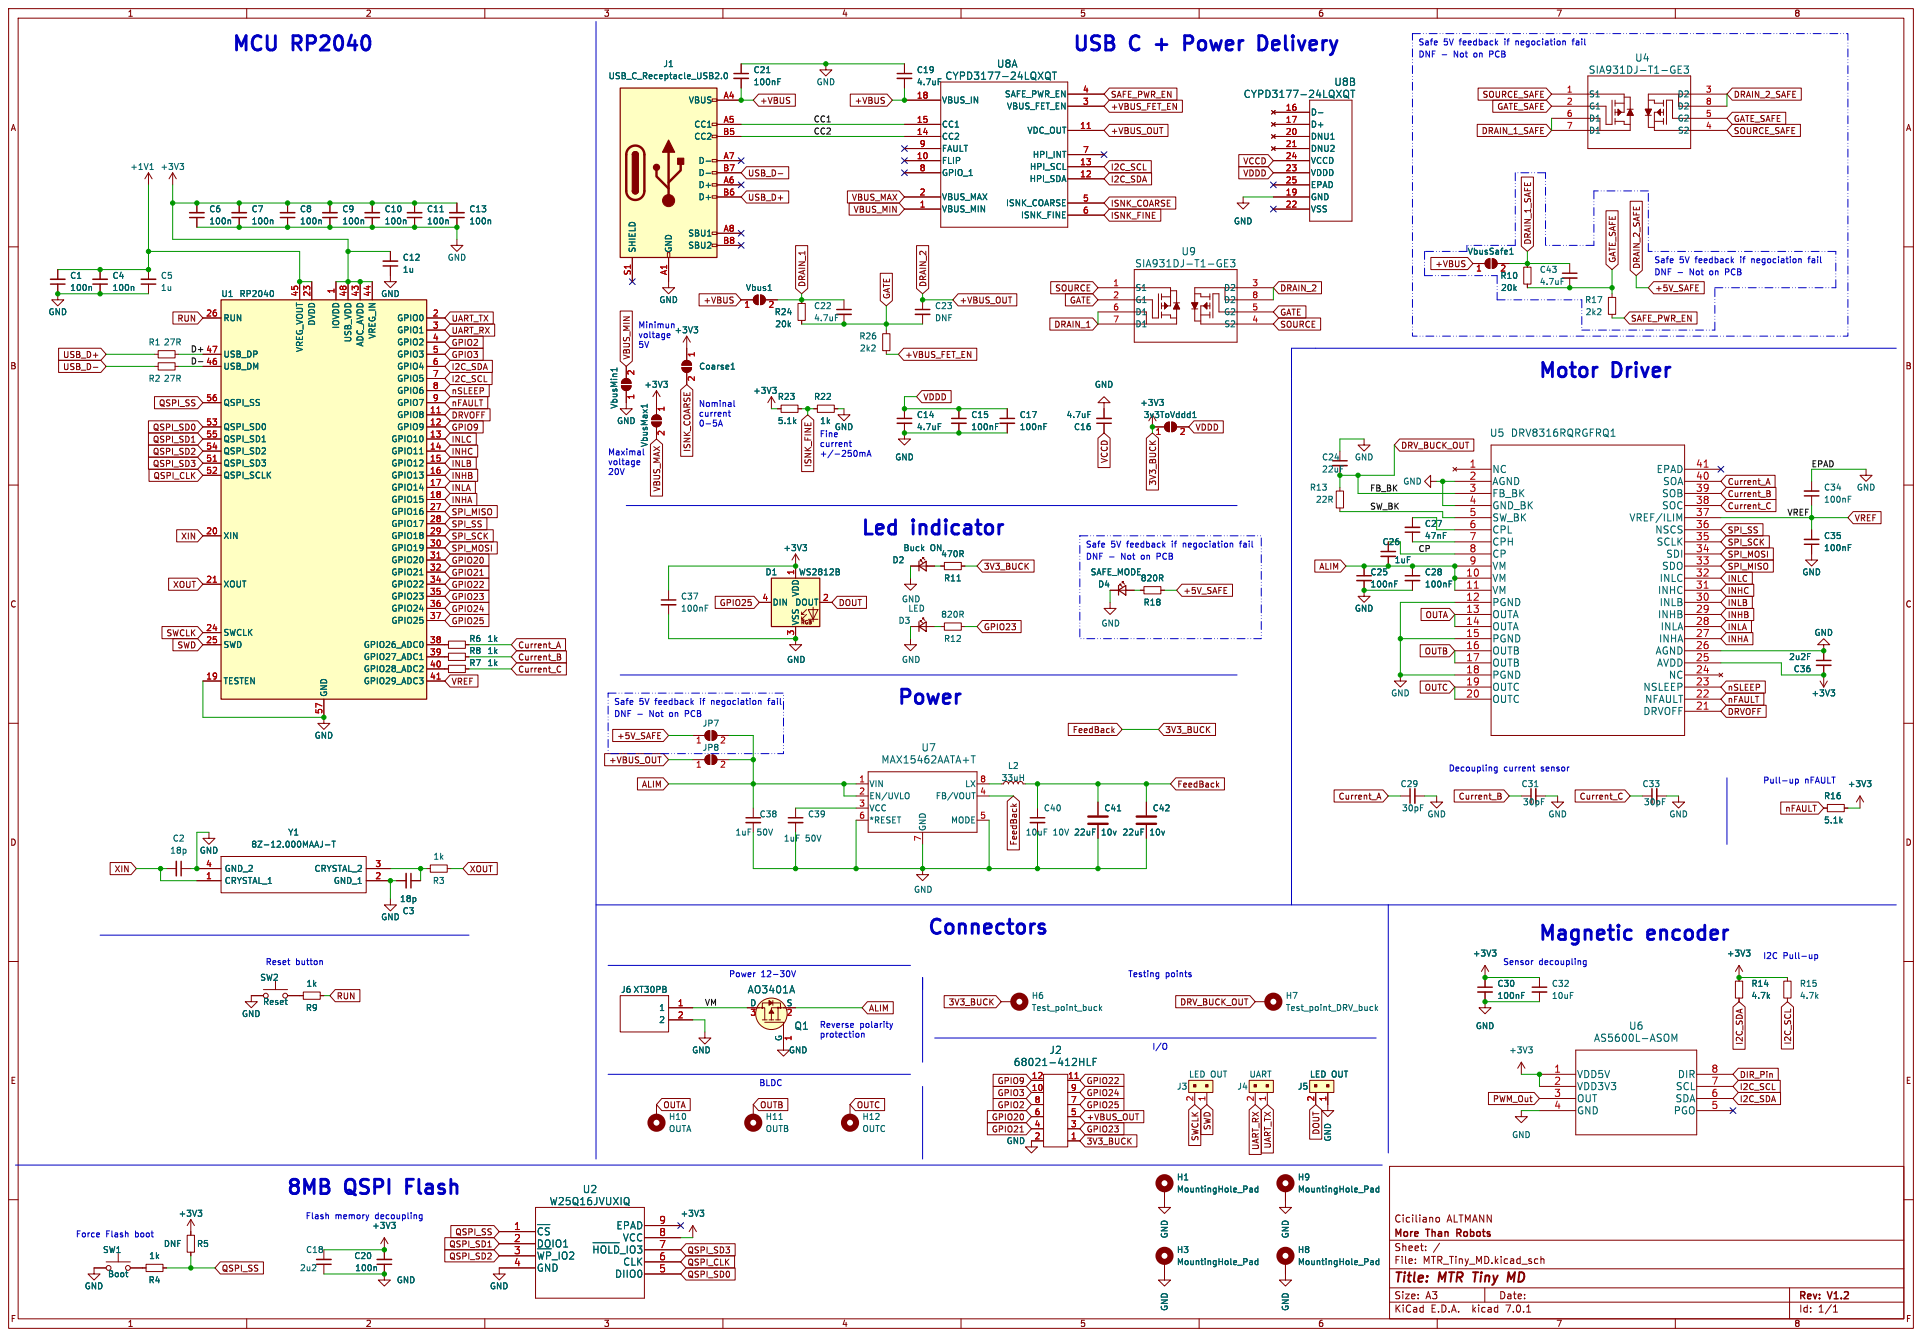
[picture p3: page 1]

DNF - Not on PCB Power

1 GPIO8 11 GPIO9 12 GPIO10 13 GPIO11 14 GPIO12 15 GPIO13 16 GPIO14 17 GPIO15 18 TESTEN 19 GPIO0 2 XIN 20 XOUT 21 DVDD 23 SWCLK 24 SWD 25 RUN 26 GPIO16 27 GPIO17 28 GPIO18 29 GPIO1 3 GPIO19 30 GPIO20 31 GPIO21 32 GPIO22 34 GPIO23 35 GPIO24 36 GPIO25 37 GPIO26_ADC0 38 GPIO27_ADC1 39 GPIO2 4 GPIO28_ADC2 40 GPIO29_ADC3 41 ADC_AVDD 43 VREG_IN 44 VREG_VOUT 45 USB_DM 46 USB_DP 47 USB_VDD 48 GPIO3 5 QSPI_SD3 51 QSPI_SCLK 52 QSPI_SD0 53 QSPI_SD2 54 QSPI_SD1 55 QSPI_SS 56 GND 57 GPIO4 6 GPIO5 7 GPIO6 8 GPIO7 9 U1 RP2040

1 GPIO8 11 GPIO9 12 GPIO10 13 GPIO11 14 GPIO12 15 GPIO13 16 GPIO14 17 GPIO15 18 TESTEN 19 GPIO0 2 XIN 20 XOUT 21 DVDD 23 SWCLK 24 SWD 25 RUN 26 GPIO16 27 GPIO17 28 GPIO18 29 GPIO1 3 GPIO19 30 GPIO20 31 GPIO21 32 GPIO22 34 GPIO23 35 GPIO24 36 GPIO25 37 GPIO26_ADC0 38 GPIO27_ADC1 39 GPIO2 4 GPIO28_ADC2 40 GPIO29_ADC3 41 ADC_AVDD 43 VREG_IN 44 VREG_VOUT 45 USB_DM 46 USB_DP 47 USB_VDD 48 GPIO3 5 QSPI_SD3 51 QSPI_SCLK 52 QSPI_SD0 53 QSPI_SD2 54 QSPI_SD1 55 QSPI_SS 56 GND 57 GPIO4 6 GPIO5 7 GPIO6 8 GPIO7 9 GND GND

DNF - Not on PCB
4.7k D4 SAFE_MODE

Id: 1/1 Title: MTR Tiny MD

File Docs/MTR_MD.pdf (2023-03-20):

Front | Back

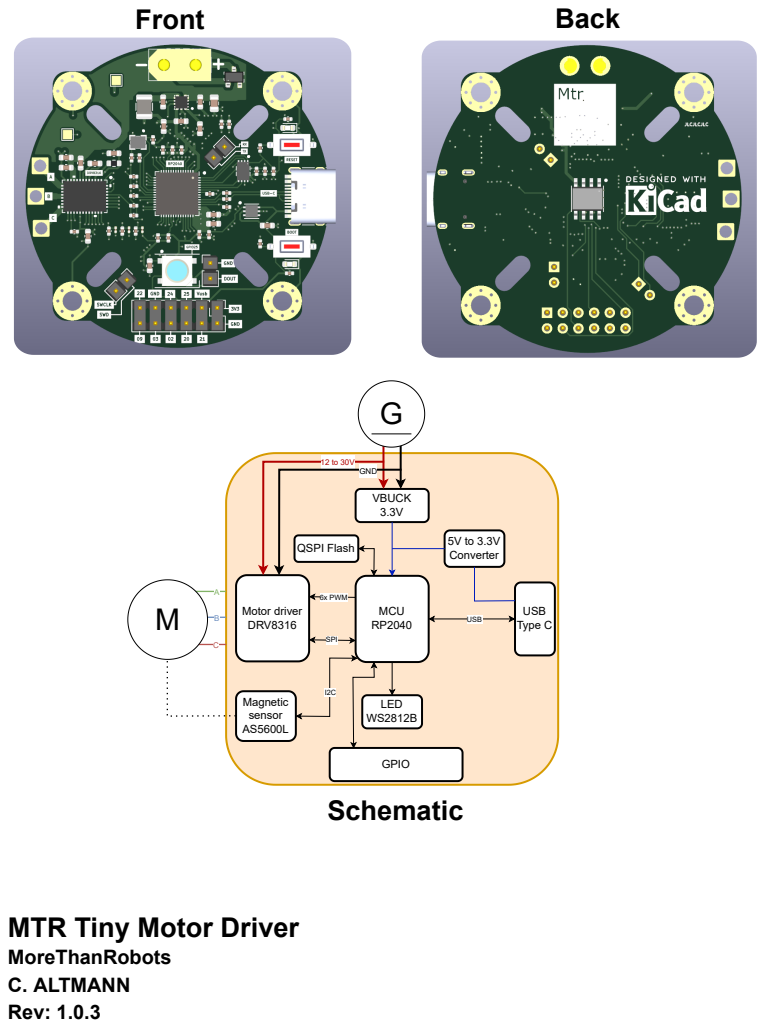
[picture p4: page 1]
Motor driver DRV8316; MCU RP2040; USB Type C; VBUCK 3.3V; QSPI Flash; LED WS2812B; GPIO; 6x PWM; SPI; USB; Magnetic sensor AS5600L; 5V to 3.3V Converter; GND; Schematic

MTR Tiny Motor Driver
MoreThanRobots
C. ALTMANN
Rev: 1.0.3

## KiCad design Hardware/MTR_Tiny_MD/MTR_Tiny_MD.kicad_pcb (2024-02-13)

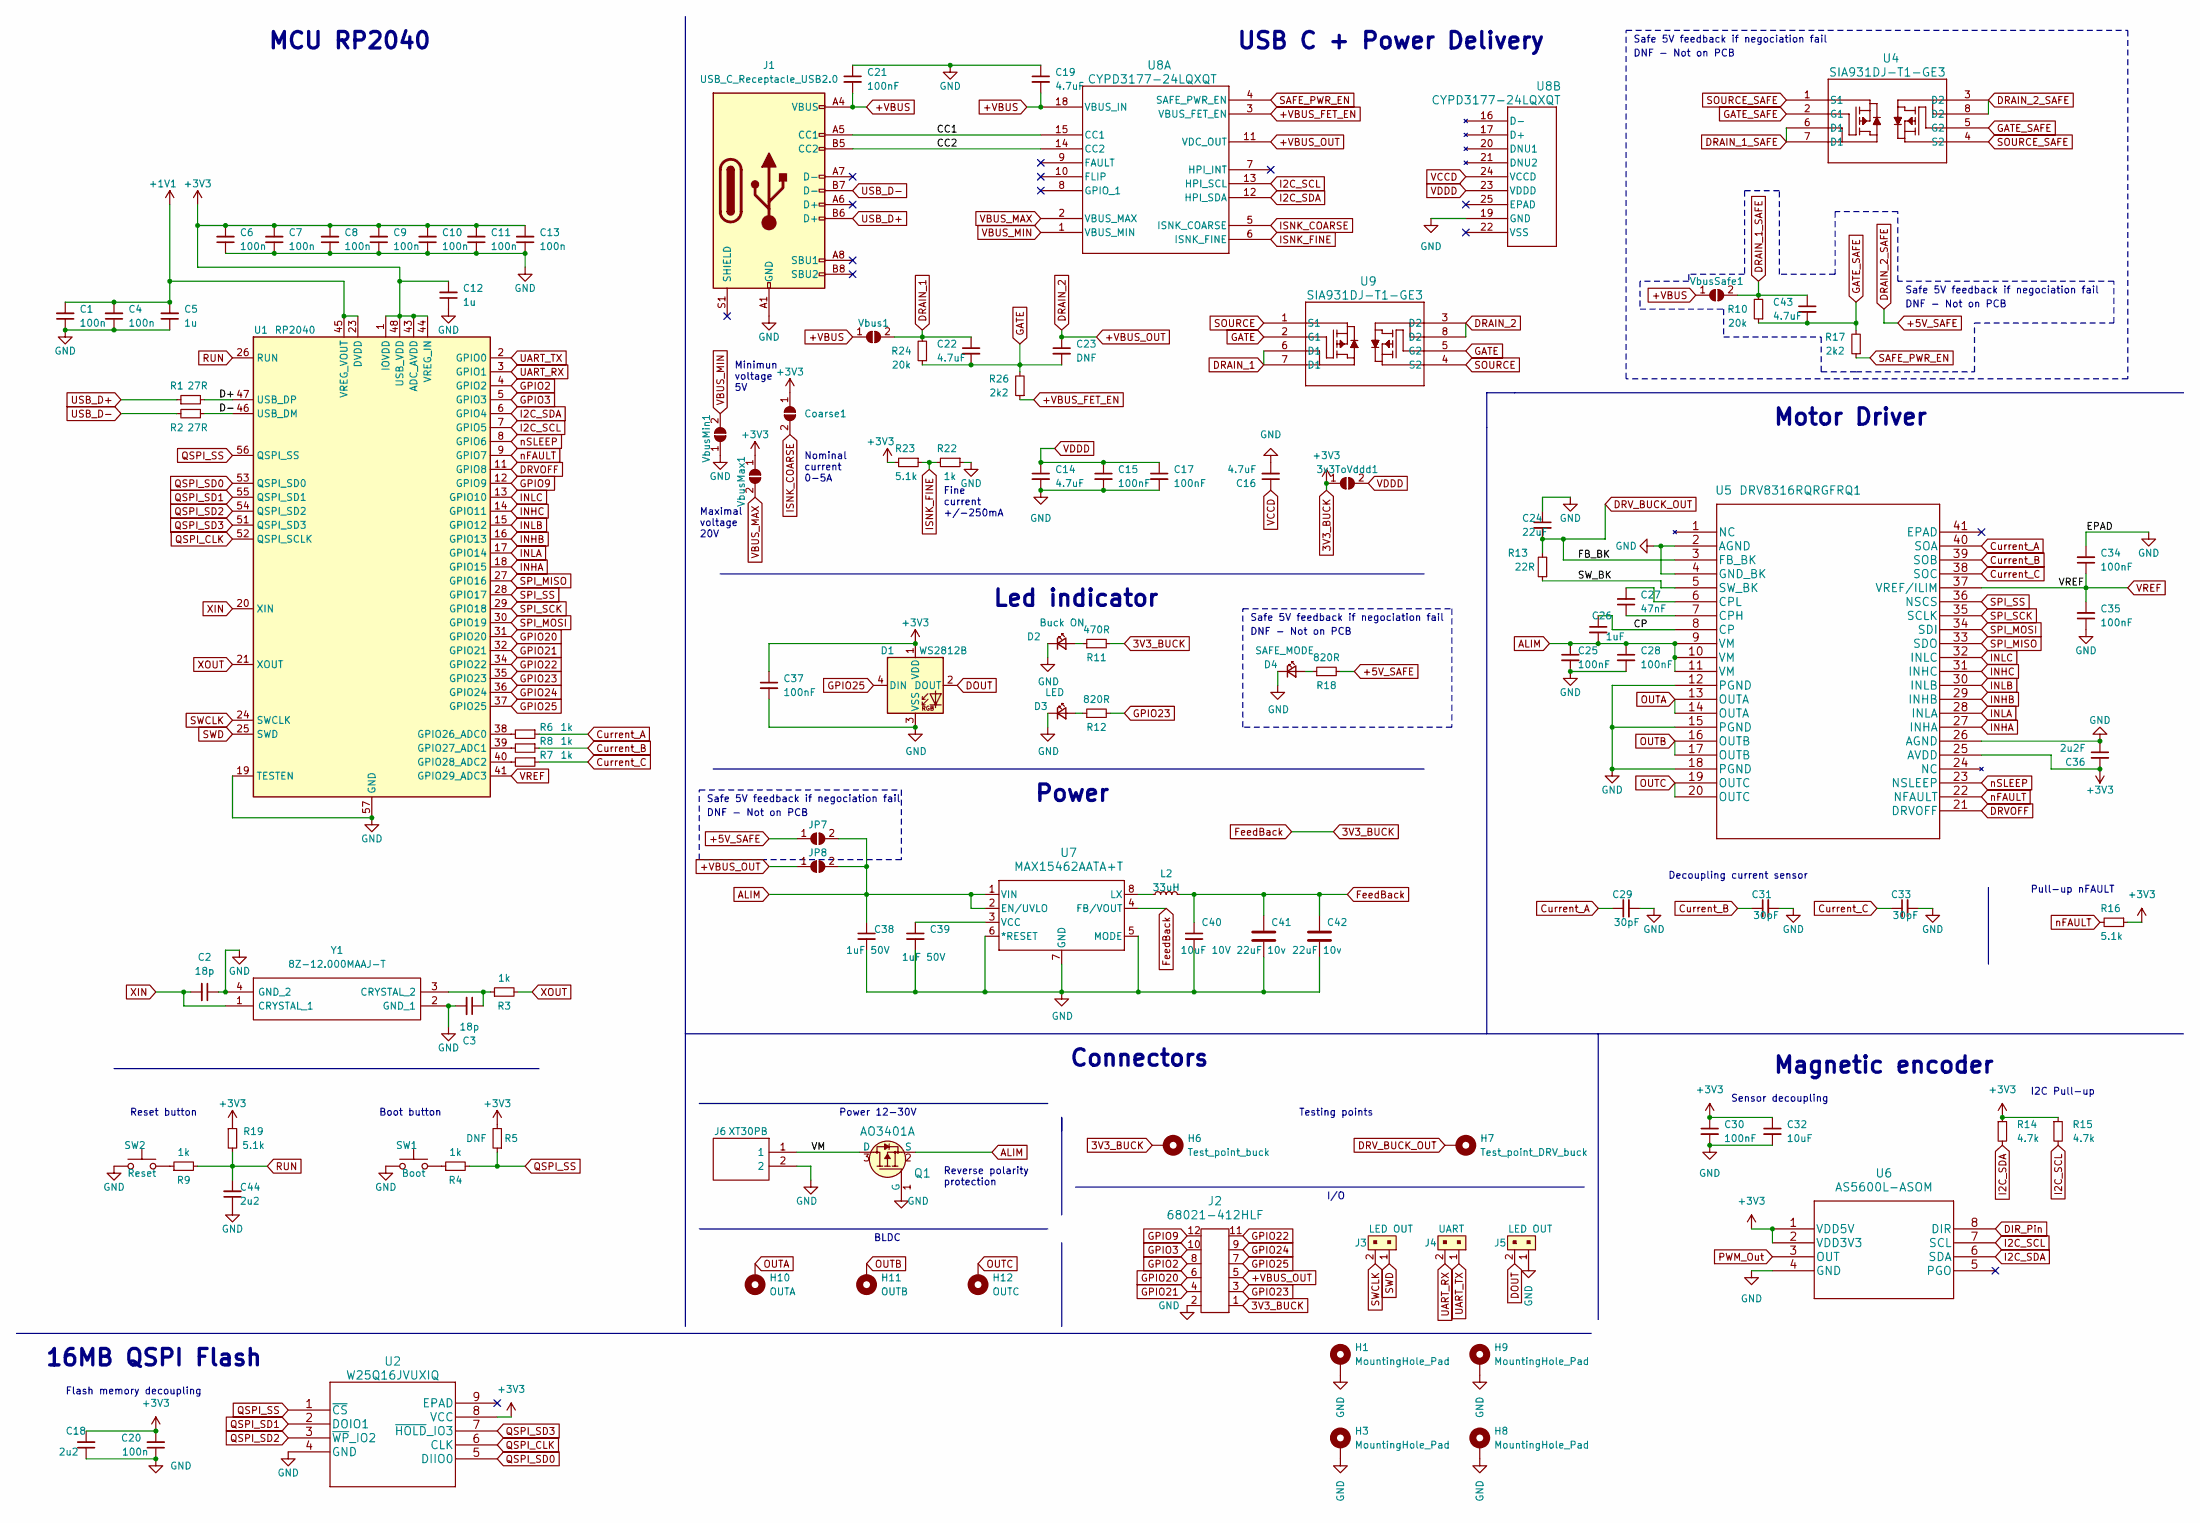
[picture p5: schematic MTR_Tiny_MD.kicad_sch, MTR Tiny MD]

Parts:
3v3ToVddd1: 3V3toVddJumper; R_0201_0603Metric
C1, C4, C6, C7, C8, C9, C10, C11, C13, C20: 100n; C_0402_1005Metric
C2, C3: 18p; C_0402_1005Metric
C5: 1u; C_0402_1005Metric
C12: 1u; C_0603_1608Metric
C14, C16, C19, C22, C43: 4.7uF; C_0402_1005Metric
C15, C17, C21, C30, C34, C35: 100nF; C_0402_1005Metric
C18, C44: 2u2; C_0402_1005Metric
C23: DNF; C_0402_1005Metric
C24: 22uF; C_0603_1608Metric
C25, C28, C37: 100nF; C_0603_1608Metric
C26: 1uF; C_0603_1608Metric
C27: 47nF; C_0603_1608Metric
C29, C31, C33: 30pF; C_0201_0603Metric
C32: 10uF; C_0402_1005Metric
C36: 2u2F; C_0603_1608Metric
C38, C39: 1uF 50V; C_1206_3216Metric
C40: 10uF 10V; C_1206_3216Metric
C41, C42: 22uF 10v; C_0603_1608Metric
Coarse1: CurrentSelect; R_0201_0603Metric
D1: WS2812B; LED_WS2812B_PLCC4_5.0x5.0mm_P3.2mm
D2: Buck ON; LED_0603_1608Metric
D3: LED; LED_0603_1608Metric
D4: SAFE_MODE; LED_0603_1608Metric
H1, H3, H8, H9: MountingHole_Pad; MountingHole_3.2mm_M3_Pad_Via
H6: Test_point_buck; TestPoint_Pad_D1.0mm
H7: Test_point_DRV_buck; TestPoint_Pad_D1.0mm
H10: OUTA; Motor_Wire_Solder_Pad
H11: OUTB; Motor_Wire_Solder_Pad
H12: OUTC; Motor_Wire_Solder_Pad
J1: USB_C_Receptacle_USB2.0; USB_C_Receptacle_HRO_TYPE-C-31-M-12
J2: 68021-412HLF; PinHeader_2x06_P2.54mm_Vertical; MPN 68021-412HLF; Digi-Key_PN 609-3355-ND
J3, J5: LED OUT; PinHeader_1x02_P2.54mm_Vertical; MPN 22-23-2021; Digi-Key_PN WM4200-ND
J4: UART; PinHeader_1x02_P2.54mm_Vertical; MPN 22-23-2021; Digi-Key_PN WM4200-ND
J6: XT30PB; CONN_XT30UPB-M_AMA; Manufacturer_Part_Number XT30PB
JP7: +5V_SAFE; R_0201_0603Metric
JP8: +VBUS_OUT; R_0201_0603Metric
L2: 33uH; L_1210_3225Metric
Q1: AO3401A; SOT-23-3; MPN AO3401A; Digi-Key_PN 785-1001-1-ND
R1, R2: 27R; R_0402_1005Metric
R3, R4, R6, R7, R8, R9, R22: 1k; R_0402_1005Metric
R5: DNF; R_0402_1005Metric
R10, R24: 20k; R_0402_1005Metric
R11: 470R; R_0402_1005Metric
R12, R18: 820R; R_0402_1005Metric
R13: 22R; R_0603_1608Metric
R14, R15: 4.7k; R_0402_1005Metric
R16, R19, R23: 5.1k; R_0402_1005Metric
R17, R26: 2k2; R_0402_1005Metric
SW1: Boot; TVAF06-A020B-R
SW2: Reset; TVAF06-A020B-R
U1: RP2040; QFN-56-1EP_7x7mm_P0.4mm_EP3.2x3.2mm
U2: W25Q16JVUXIQ
U4, U9: SIA931DJ-T1-GE3; MOSFET_T1-GE3_VIS
U5: DRV8316RQRGFRQ1
U6: AS5600L-ASOM
U7: MAX15462AATA+T; 21-0487_T822CN&plus_1_MXM
U8: CYPD3177-24LQXQT; CYPD3177-24LQXQT_CYP
Vbus1: VbusJumper; R_0201_0603Metric
VbusMax1: VbusMax; R_0201_0603Metric
VbusMin1: VbusMin; R_0201_0603Metric
VbusSafe1: VbusJumper; R_0201_0603Metric
Y1: 8Z-12.000MAAJ-T; 8Z12000MAAJT; Manufacturer_Part_Number 8Z-12.000MAAJ-T; Mouser Part Number 717-8Z-12.000MAAJ-T

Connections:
3V3_BUCK: 3v3ToVddd1.1 (A), C6.2, C7.2, C8.2, C9.2, C10.2, C11.2, C12.2, C13.2, C18.2, C20.2, C30.1, C32.1, C36.2, C37.1, C40.1, C41.1, C42.1, Coarse1.1 (A), D1.1 (VDD), H6.1, J2.1, L2.2, R5.2, R11.2, R14.1, R15.1, R16.1, R19.1, R23.2, U1.1 (IOVDD), U1.10 (IOVDD), U1.22 (IOVDD), U1.33 (IOVDD), U1.42 (IOVDD), U1.43 (ADC_AVDD), U1.44 (VREG_IN), U1.48 (USB_VDD), U1.49 (IOVDD), U2.8 (VCC), U5.25 (AVDD), U6.1 (VDD5V), U6.2 (VDD3V3), U7.4 (FB/VOUT), VbusMax1.1 (A)
+1V1: C1.2, C4.2, C5.2, U1.23 (DVDD), U1.45 (VREG_VOUT), U1.50 (DVDD)
+VBUS: C19.2, C21.2, J1.A4 (VBUS), J1.A9 (VBUS), J1.B4 (VBUS), J1.B9 (VBUS), U8.18 (VBUS_IN), Vbus1.1 (A), VbusSafe1.1 (A)
+VBUS_FET_EN: R26.1, U8.3 (VBUS_FET_EN)
+VBUS_OUT: C23.1, J2.5, JP8.1 (A), U8.11 (VDC_OUT), U9.3 (D2), U9.8 (D2)
/CC1: J1.A5 (CC1), U8.15 (CC1)
/CC2: J1.B5 (CC2), U8.14 (CC2)
/CP: C26.1, U5.8 (CP)
/D+: R1.2, U1.47 (USB_DP)
/D-: R2.1, U1.46 (USB_DM)
/SW_BK: R13.1, U5.5 (SW_BK)
/VM: J6.1, Q1.3 (D)
ALIM: C25.1, C26.2, C28.1, C38.1, JP7.2 (B), JP8.2 (B), Q1.2 (S), U5.9 (VM), U5.10 (VM), U5.11 (VM), U7.1 (VIN), U7.2 (EN/UVLO)
Current_A: C29.1, R6.1, U5.40 (SOA)
Current_B: C31.1, R7.1, U5.39 (SOB)
Current_C: C33.1, R8.1, U5.38 (SOC)
DIR_Pin: U6.8 (DIR)
DOUT: D1.2 (DOUT), J5.2
DRAIN_1: C22.1, R24.2, U9.6 (D1), U9.7 (D1), Vbus1.2 (B)
DRVOFF: U1.11 (GPIO8), U5.21 (DRVOFF)
DRV_BUCK_OUT: C24.2, H7.1, R13.2, U5.3 (FB_BK)
GATE: C22.2, C23.2, R24.1, R26.2, U9.2 (G1), U9.5 (G2)
GND: C1.1, C2.1, C3.2, C4.1, C5.1, C6.1, C7.1, C8.1, C9.1, C10.1, C11.1, C12.1, C13.1, C14.2, C15.2, C16.2, C17.2, C18.1, C19.1, C20.1, C21.1, C24.1, C25.2, C28.2, C29.2, C30.2, C31.2, C32.2, C33.2, C34.2, C35.1, C36.1, C37.2, C38.2, C39.2, C40.2, C41.2, C42.2, C44.1, D1.3 (VSS), D2.1 (K), D3.1 (K), D4.1 (K), H1.1, H3.1, H8.1, H9.1, J1.A1 (GND), J1.A12 (GND), J1.B1 (GND), J1.B12 (GND), J2.2, J5.1, J6.2, Q1.1 (G), R22.1, SW1.1, SW2.1, U1.19 (TESTEN), U1.57 (GND), U2.4 (GND), U5.2 (AGND), U5.4 (GND_BK), U5.12 (PGND), U5.15 (PGND), U5.18 (PGND), U5.26 (AGND), U6.4 (GND), U7.5 (MODE), U7.6 (*RESET), U7.7 (GND), U8.19 (GND), VbusMin1.1 (A), Y1.2 (GND_1), Y1.4 (GND_2)
GPIO2: J2.8, U1.4 (GPIO2)
GPIO3: J2.10, U1.5 (GPIO3)
GPIO9: J2.12, U1.12 (GPIO9)
GPIO20: J2.6, U1.31 (GPIO20)
GPIO21: J2.4, U1.32 (GPIO21)
GPIO22: J2.11, U1.34 (GPIO22)
GPIO23: J2.3, R12.2, U1.35 (GPIO23)
GPIO24: J2.9, U1.36 (GPIO24)
GPIO25: D1.4 (DIN), J2.7, U1.37 (GPIO25)
I2C_SCL: R15.2, U1.7 (GPIO5), U6.7 (SCL), U8.13 (HPI_SCL)
I2C_SDA: R14.2, U1.6 (GPIO4), U6.6 (SDA), U8.12 (HPI_SDA)
INHA: U1.18 (GPIO15), U5.27 (INHA)
INHB: U1.16 (GPIO13), U5.29 (INHB)
INHC: U1.14 (GPIO11), U5.31 (INHC)
INLA: U1.17 (GPIO14), U5.28 (INLA)
INLB: U1.15 (GPIO12), U5.30 (INLB)
INLC: U1.13 (GPIO10), U5.32 (INLC)
ISNK_COARSE: Coarse1.2 (B), U8.5 (ISNK_COARSE)
ISNK_FINE: R22.2, R23.1, U8.6 (ISNK_FINE)
unnamed: C43.1, R10.2, U4.6 (D1), U4.7 (D1), VbusSafe1.2 (B)
unnamed: C43.2, R10.1, R17.2, U4.2 (G1), U4.5 (G2)
unnamed: D2.2 (A), R11.1
unnamed: D3.2 (A), R12.1
unnamed: D4.2 (A), R18.1
unnamed: JP7.1 (A), R18.2, U4.3 (D2), U4.8 (D2)
unnamed: R4.1, SW1.2
unnamed: R9.1, SW2.2
unnamed: R6.2, U1.38 (GPIO26_ADC0)
unnamed: R7.2, U1.39 (GPIO27_ADC1)
unnamed: R8.2, U1.40 (GPIO28_ADC2)
unnamed: U4.1 (S1), U4.4 (S2)
unnamed: C27.1, U5.7 (CPH)
unnamed: C27.2, U5.6 (CPL)
unnamed: L2.1, U7.8 (LX)
unnamed: C39.1, U7.3 (VCC)
unnamed: C3.1, R3.1, Y1.3 (CRYSTAL_2)
OUTA: H10.1, U5.13 (OUTA), U5.14 (OUTA)
OUTB: H11.1, U5.16 (OUTB), U5.17 (OUTB)
OUTC: H12.1, U5.19 (OUTC), U5.20 (OUTC)
PWM_Out: U6.3 (OUT)
QSPI_CLK: U1.52 (QSPI_SCLK), U2.6 (CLK)
QSPI_SD0: U1.53 (QSPI_SD0), U2.5 (DIIO0)
QSPI_SD1: U1.55 (QSPI_SD1), U2.2 (DOIO1)
QSPI_SD2: U1.54 (QSPI_SD2), U2.3 (~WP_IO2)
QSPI_SD3: U1.51 (QSPI_SD3), U2.7 (~HOLD_IO3)
QSPI_SS: R4.2, R5.1, U1.56 (QSPI_SS), U2.1 (~CS)
RUN: C44.2, R9.2, R19.2, U1.26 (RUN)
SAFE_PWR_EN: R17.1, U8.4 (SAFE_PWR_EN)
SOURCE: U9.1 (S1), U9.4 (S2)
SPI_MISO: U1.27 (GPIO16), U5.33 (SDO)
SPI_MOSI: U1.30 (GPIO19), U5.34 (SDI)
SPI_SCK: U1.29 (GPIO18), U5.35 (SCLK)
SPI_SS: U1.28 (GPIO17), U5.36 (NSCS)
SWCLK: J3.2, U1.24 (SWCLK)
SWD: J3.1, U1.25 (SWD)
UART_RX: J4.2, U1.3 (GPIO1)
UART_TX: J4.1, U1.2 (GPIO0)
USB_D+: J1.B6 (D+), R1.1
USB_D-: J1.B7 (D-), R2.2
VBUS_MAX: U8.2 (VBUS_MAX), VbusMax1.2 (B)
VBUS_MIN: U8.1 (VBUS_MIN), VbusMin1.2 (B)
VCCD: C16.1, U8.24 (VCCD)
VDDD: 3v3ToVddd1.2 (B), C14.1, C15.1, C17.1, U8.23 (VDDD)
VREF: C34.1, C35.2, U1.41 (GPIO29_ADC3), U5.37 (VREF/ILIM)
XIN: C2.2, U1.20 (XIN), Y1.1 (CRYSTAL_1)
XOUT: R3.2, U1.21 (XOUT)
nFAULT: R16.2, U1.9 (GPIO7), U5.22 (NFAULT)
nSLEEP: U1.8 (GPIO6), U5.23 (NSLEEP)

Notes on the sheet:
DNF - Not on PCB
Sensor decoupling
Safe 5V feedback if negociation fail
Minimun voltage 5V
Connectors
Fine current +/-250mA
I/O
Reverse polarity protection
USB C + Power Delivery
Power 12-30V
Reset button
MCU RP2040
Motor Driver
Nominal current 0-5A
Decoupling current sensor
Flash memory decoupling
Power
BLDC
16MB QSPI Flash
I2C Pull-up
Maximal voltage 20V
Pull-up nFAULT
Led indicator
Testing points
Magnetic encoder
Boot button

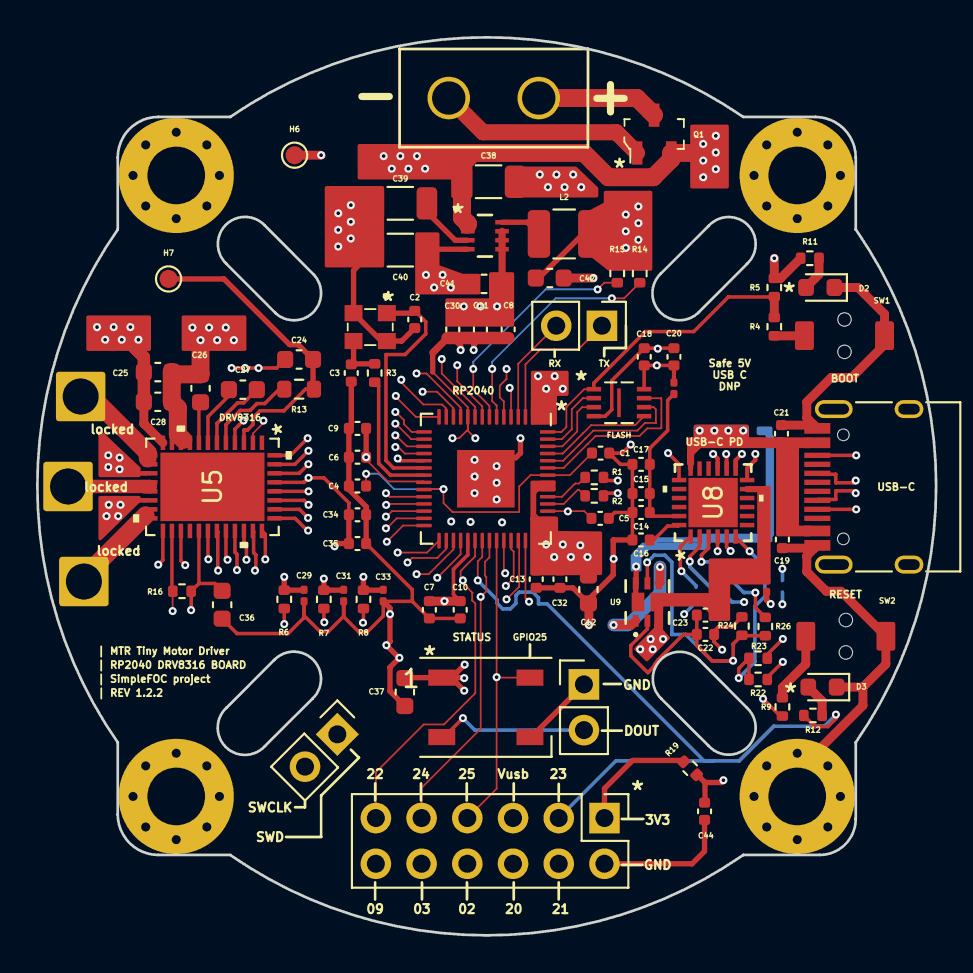
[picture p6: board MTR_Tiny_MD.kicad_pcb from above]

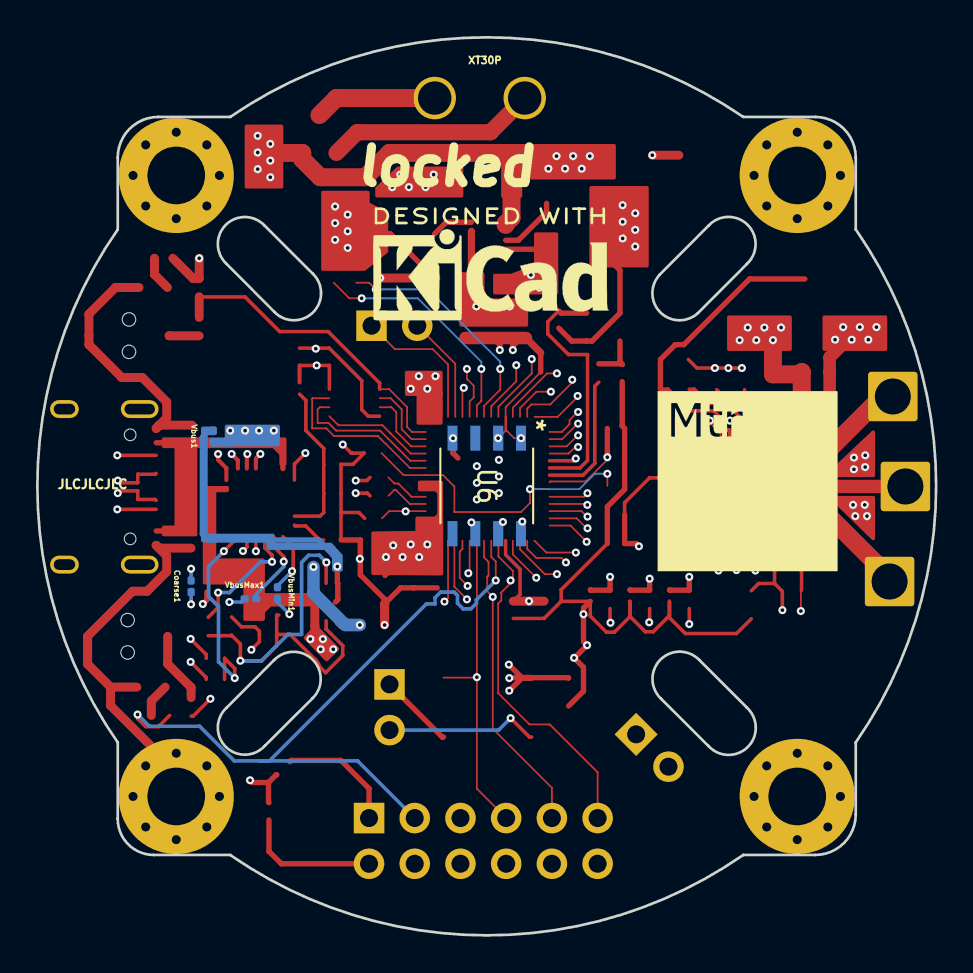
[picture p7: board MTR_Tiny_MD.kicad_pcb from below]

Board: 6 copper layers, 49.9 x 49.9 mm, 99 parts (5 on the bottom side), 83 nets.

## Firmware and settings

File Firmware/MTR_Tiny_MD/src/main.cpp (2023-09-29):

#include <Arduino.h>
#include <SimpleFOC.h>
#include <Wire.h>
#include <SPI.h>
#include <SimpleFOCDrivers.h>
#include "drivers/drv8316/drv8316.h"
#include <Adafruit_NeoPixel.h>
#include "Tiny_MD_Params.h"

#define TARGET_RP2040
#define SIMPLEFOC_DRV8316

// Prototype for the function
void printDRV8316Status();

// NeoPixel
Adafruit_NeoPixel pixels(NUMPIXELS, WS2812B_PIN, NEO_GRB + NEO_KHZ800);

// magnetic sensor instance - MagneticSensorI2C
MagneticSensorI2C sensor = MagneticSensorI2C(AS5600_I2C);

// BLDC motor & driver instance
BLDCMotor motor = BLDCMotor(13);
DRV8316Driver6PWM driver = DRV8316Driver6PWM(DRV8316_INH_A, DRV8316_INL_A, DRV8316_INH_B, DRV8316_INL_B, DRV8316_INH_C, DRV8316_INL_C, DRV8316_SPI_CS, false, DRV8316_DRV_OFF, DRV8316_nFAULT);

// velocity set point variable
float target_velocity = 0;

// instantiate the commander
Commander command = Commander(Serial);
void doTarget(char *cmd) { command.scalar(&target_velocity, cmd); }

void setup()
{
	// Set pin DRV8316_nSLEEP as output and set it high to enable the DRV8316
	pinMode(DRV8316_nSLEEP, OUTPUT);
	digitalWrite(DRV8316_nSLEEP, HIGH);

	delay(1000);

	// initialise magnetic sensor hardware
	sensor.init();
	// link the motor to the sensor
	motor.linkSensor(&sensor);

	// driver config
	// power supply voltage [V]
	driver.voltage_power_supply = 24;
	driver.init();
	// link the motor and the driver
	motor.linkDriver(&driver);

	// set motion control loop to be used
	motor.controller = MotionControlType::velocity;

	// contoller configuration
	// default parameters in defaults.h

	// velocity PI controller parameters
	motor.PID_velocity.P = 0.2f;
	motor.PID_velocity.I = 20;
	motor.PID_velocity.D = 0;
	// default voltage_power_supply
	motor.voltage_limit = 6;
	// jerk control using voltage voltage ramp
	// default value is 300 volts per sec  ~ 0.3V per millisecond
	motor.PID_velocity.output_ramp = 1000;

	// velocity low pass filtering
	// default 5ms - try different values to see what is the best.
	// the lower the less filtered
	motor.LPF_velocity.Tf = 0.01f;

	// use monitoring with serial
	Serial.begin(115200);

	// comment out if not needed
	motor.useMonitoring(Serial);

	// initialize motor
	motor.init();
	// align sensor and start FOC
	motor.initFOC();

	// add target command T
	command.add('T', doTarget, "target velocity");

	Serial.println(F("Motor ready."));
	Serial.println(F("Set the target velocity using serial terminal:"));
	_delay(1000);
	pixels.begin(); // INITIALIZE NeoPixel strip object (REQUIRED)

	printDRV8316Status();
}

void loop()
{
	Red		= random(0, 255);
	Green	= random(0, 255);
	Blue	= random(0, 255);
	pixels.clear(); // Set all pixel colors to 'off'
	pixels.setPixelColor(0, pixels.Color(Red, Green, Blue));
 	pixels.show();   // Send the updated pixel colors to the hardware.

	// Sensor update
	sensor.update();

	Serial.print((sensor.getMechanicalAngle()*180/PI));
	Serial.print(",");
	Serial.print((sensor.getVelocity()*180/PI));
	Serial.print(",");
	Serial.print((sensor.getFullRotations()));
	Serial.print(",");
	Serial.print((motor.shaft_angle*180/PI));
	Serial.print(",");
	Serial.println((motor.shaft_velocity*180/PI));

	// main FOC algorithm function
	motor.loopFOC();

	// Motion control function
	motor.move(target_velocity);

	// function intended to be used with serial plotter to monitor motor variables
	//motor.monitor();

	// user communication
	command.run();
	
	//delay(500);

}

void printDRV8316Status()
{
	DRV8316Status status = driver.getStatus();
	Serial.println("DRV8316 Status:");
	Serial.print("Fault: ");
	Serial.println(status.isFault());
	Serial.print("Buck Error: ");
	Serial.print(status.isBuckError());
	Serial.print("  Undervoltage: ");
	Serial.print(status.isBuckUnderVoltage());
	Serial.print("  OverCurrent: ");
	Serial.println(status.isBuckOverCurrent());
	Serial.print("Charge Pump UnderVoltage: ");
	Serial.println(status.isChargePumpUnderVoltage());
	Serial.print("OTP Error: ");
	Serial.println(status.isOneTimeProgrammingError());
	Serial.print("OverCurrent: ");
	Serial.print(status.isOverCurrent());
	Serial.print("  Ah: ");
	Serial.print(status.isOverCurrent_Ah());
	Serial.print("  Al: ");
	Serial.print(status.isOverCurrent_Al());
	Serial.print("  Bh: ");
	Serial.print(status.isOverCurrent_Bh());
	Serial.print("  Bl: ");
	Serial.print(status.isOverCurrent_Bl());
	Serial.print("  Ch: ");
	Serial.print(status.isOverCurrent_Ch());
	Serial.print("  Cl: ");
	Serial.println(status.isOverCurrent_Cl());
	Serial.print("OverTemperature: ");
	Serial.print(status.isOverTemperature());
	Serial.print("  Shutdown: ");
	Serial.print(status.isOverTemperatureShutdown());
	Serial.print("  Warning: ");
	Serial.println(status.isOverTemperatureWarning());
	Serial.print("OverVoltage: ");
	Serial.println(status.isOverVoltage());
	Serial.print("PowerOnReset: ");
	Serial.println(status.isPowerOnReset());
	Serial.print("SPI Error: ");
	Serial.print(status.isSPIError());
	Serial.print("  Address: ");
	Serial.print(status.isSPIAddressError());
	Serial.print("  Clock: ");
	Serial.print(status.isSPIClockFramingError());
	Serial.print("  Parity: ");
	Serial.println(status.isSPIParityError());
	if (status.isFault())
		driver.clearFault();
	delayMicroseconds(1); // ensure 400ns delay
	DRV8316_PWMMode val = driver.getPWMMode();
	Serial.print("PWM Mode: ");
	Serial.println(val);
	delayMicroseconds(1); // ensure 400ns delay
	bool lock = driver.isRegistersLocked();
	Serial.print("Lock: ");
	Serial.println(lock);
}

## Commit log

2023-02-26 new DCDC convert
    [BOM.xlsx, MTR_Tiny_MD.kicad_sch]
2023-03-20 add drawing.io and footprint & 3D model to project
    [MTR_Tiny_MD.kicad_pcb, MTR_Tiny_MD.kicad_sch]
2023-04-29 Add new Vbuck
    LMR36506 to MAX15462AATA+T
    [MTR_Tiny_MD.kicad_pcb, MTR_Tiny_MD.kicad_sch]
2023-05-14 Silkscreen labelling - RFP
    Ready For Production Rev 1.1
    [MTR_Tiny_MD-B_Cu.gbr, MTR_Tiny_MD-B_Mask.gbr, MTR_Tiny_MD-B_Paste.gbr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]
2023-08-09 add local libraries and NeoPixel Hello World
    [MTR_Tiny_MD.csv]
2023-09-02 add usb C PD controler
    [MTR_Tiny_MD-B_Cu.gbr, MTR_Tiny_MD-B_Mask.gbr, MTR_Tiny_MD-B_Paste.gbr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]
2023-09-14 Update design, add PD controler, correct SPI
    [MTR_Tiny_MD.kicad_pcb, MTR_Tiny_MD.kicad_sch]
2023-09-14 Updated schematic

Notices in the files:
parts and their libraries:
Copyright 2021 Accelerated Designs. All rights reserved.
